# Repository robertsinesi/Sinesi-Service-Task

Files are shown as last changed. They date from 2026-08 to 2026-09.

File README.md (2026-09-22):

# KLM SRAM Expansion — Service Task

Belle II KLM service work · Instrumentation Development Lab, University of Hawai'i at Mānoa

## Overview

The KLM scintillator readout currently shares a single SRAM between the Bus A and
Bus B firmware modules through the SCROD FPGA. During multi-strip hits, pedestal
fetching becomes the rate-limiting step in waveform processing. This project adds
a second SRAM on an auxiliary daughtercard so each bus has its own memory path,
along with the power-distribution hardware needed to supply it.

Three boards make up the system:

| Board | Function |
| --- | --- |
| **Aux SRAM daughtercard** | Mounts to the spare 80-pin mezzanine connector on the scintillator motherboard; carries the second SRAM and a local 3.3 V regulator |
| **RTM +5 V board** | Rear transition module; taps +5 V from the crate backplane, fuses it, and feeds the wiring harness |
| **2-pole fanout board** | Splits the 12 AWG trunk into 22 AWG drops, one per SRAM card |

**Board design credit:** all three boards were designed by Chris Ketter (UH Mānoa),
with contributions from Horacio Ledesma. My role is prototype testing and design
finalization.

## Scope of this qualification task

Testing and validation:

- Test the prototype SRAM expansion board on the UH KLM testbench
- Test the associated RTM and power-distribution boards
- Verify electrical connections and power delivery across the full chain
- Confirm correct operation with the dedicated SRAM firmware

Finalization:

- Feed prototype results back into the board designs
- Help finalize assembly procedures ahead of the production run

Superseded board revisions are kept in the `Old_Boards_Moved_<M-D-YY>/` folders (dated by when they were superseded, each with a short README); current files are in `Finalized-Boards/`.

## Deliverable

- Finalized board designs
- Production of the boards
- Installation of the boards

## After the qualification task

Continued contribution to board production, testing, and installation as part of
ongoing KLM service work.

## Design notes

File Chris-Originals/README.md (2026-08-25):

# KLM SRAM Exp

## KLM SRAM Upgrade project
We are using a spare 80-pin connector on the motherboard to double the amount and bandwidth of SRAM available to our FPGA.

## Firmware
The new firmware for this project has been created in the main SCROD FW repository under the branch feature/SRAM_upgrade.

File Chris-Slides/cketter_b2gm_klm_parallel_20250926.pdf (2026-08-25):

Chris Ketter & Horacio Ledesma University of Hawaii at Mānoa

## KLM Scintillator SRAM Expansion

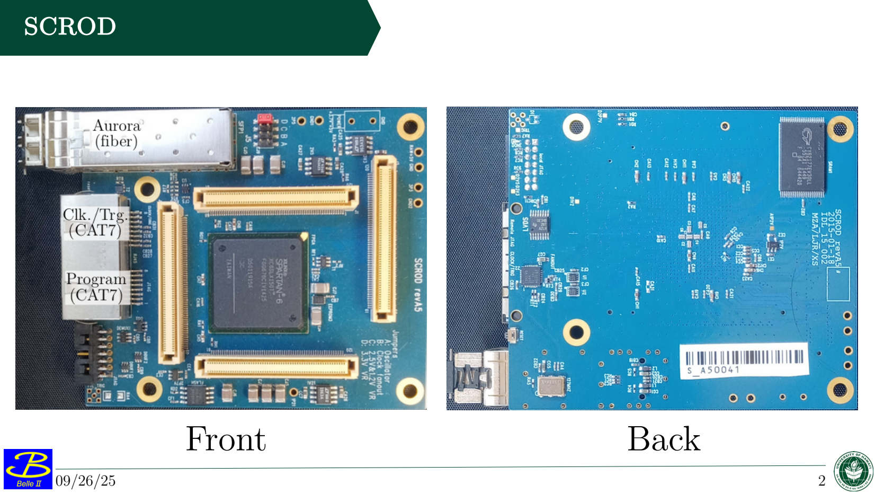
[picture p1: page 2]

09/26/25 | 2

SCROD

Front | Back

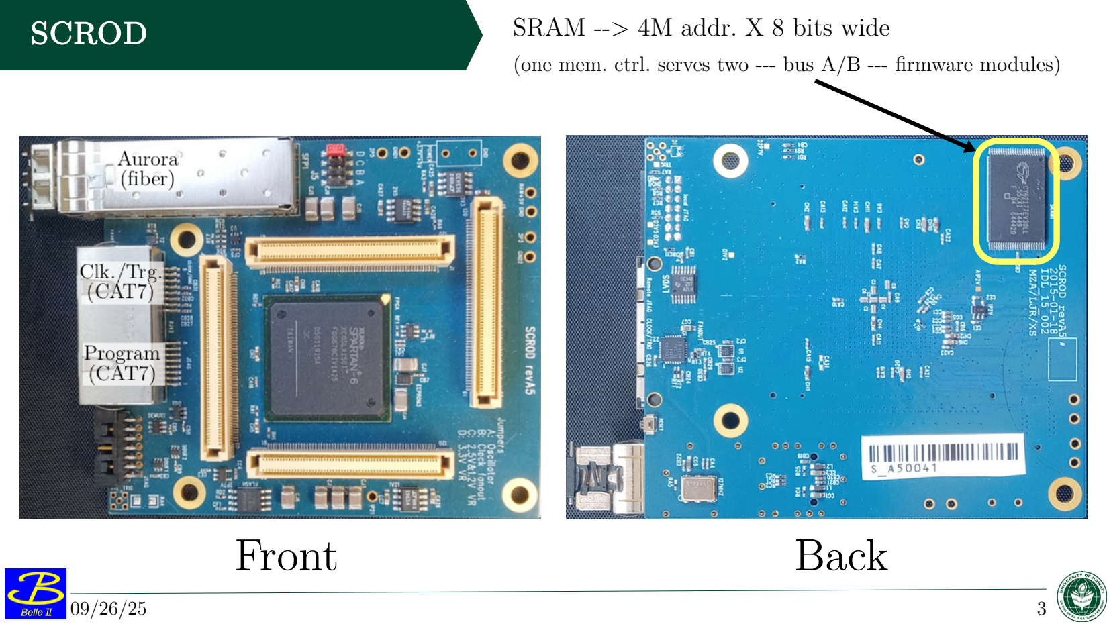
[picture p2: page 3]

SCROD | SRAM --> 4M addr. X 8 bits wide (one mem. ctrl. serves two --- bus A/B --- firmware modules)
Front | Back

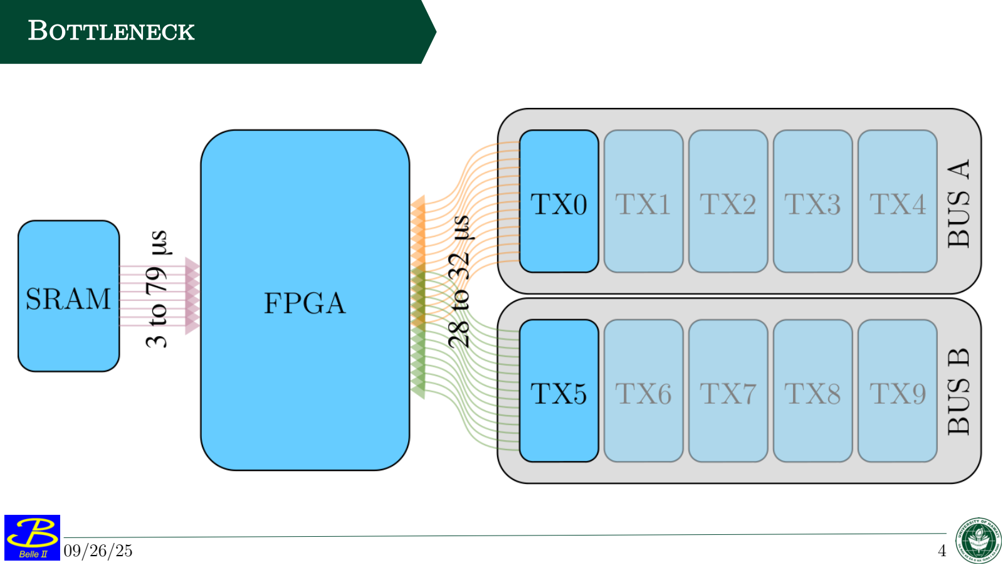
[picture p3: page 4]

Bottleneck

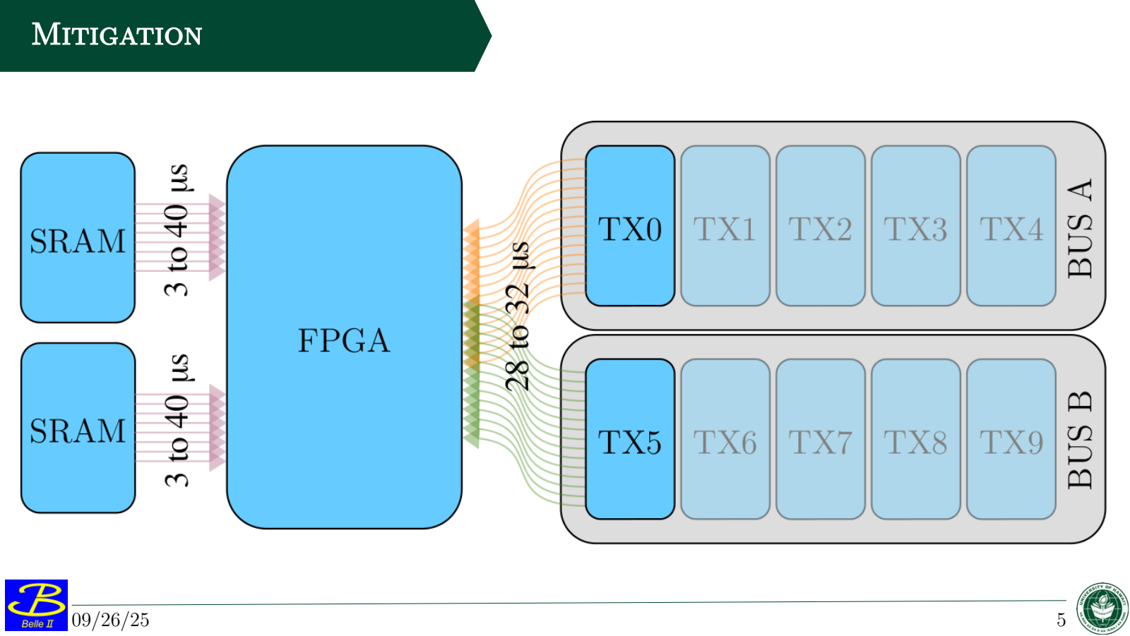
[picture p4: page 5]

Mitigation

SCROD SRAM Expansion
Board

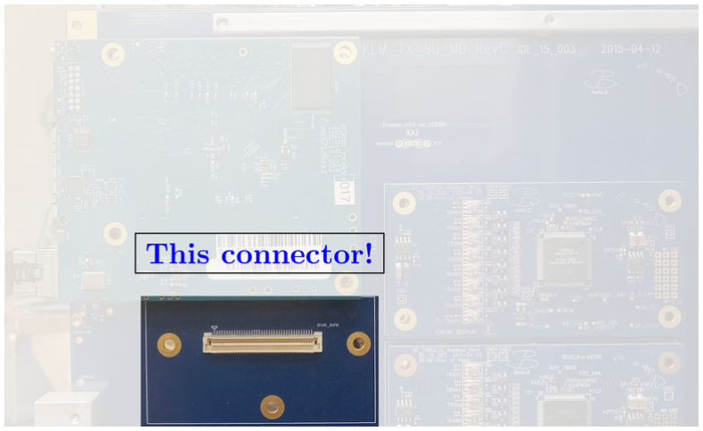
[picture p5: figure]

Important for multi-strip hits wherein pedestal fetching
becomes the bottleneck
The US-Belle II operations budget confirmed $15k for the project

Design requirements

At least 2M X 8 in memory depth
As fast as existing SRAM
Installation must be possible without uncabling (and thereby possibly damaging) readout electronics
External 3.3 V power supply must meet same installation criteria

Design requirements
At least 2M X 8 in memory depth
As fast as existing SRAM
Installation must be possible without uncabling (and thereby possibly damaging) readout electronics
External 3.3 V power supply must meet same installation criteria

(Extra --- wish list --- item: Can we install standoffs under SCROD at the same time?
→Recall persistent issue with SCRODs coming unseated!)

## Ease of installation?

Access Test (Last July)

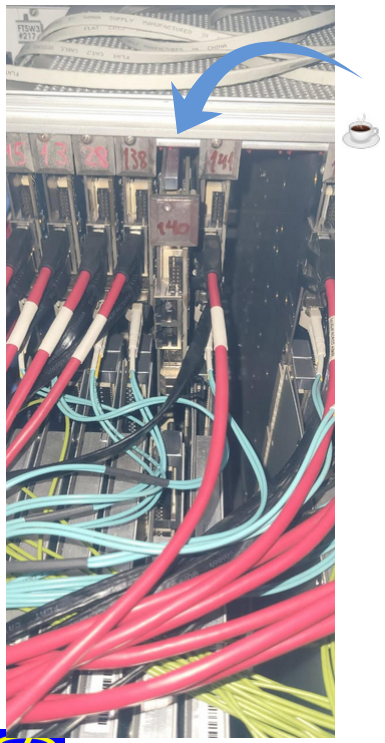
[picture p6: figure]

Slid out a central
board in EB0

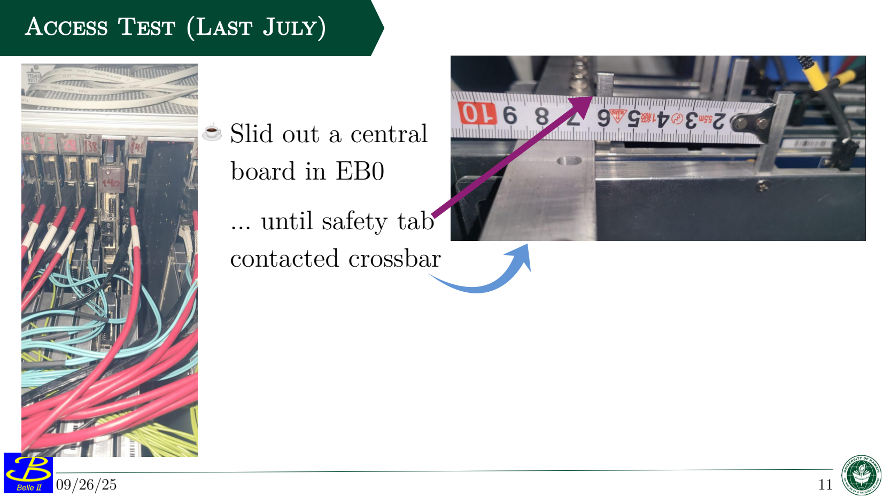
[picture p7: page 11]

Access Test (Last July)

Slid out a central
board in EB0
... until safety tab
contacted crossbar

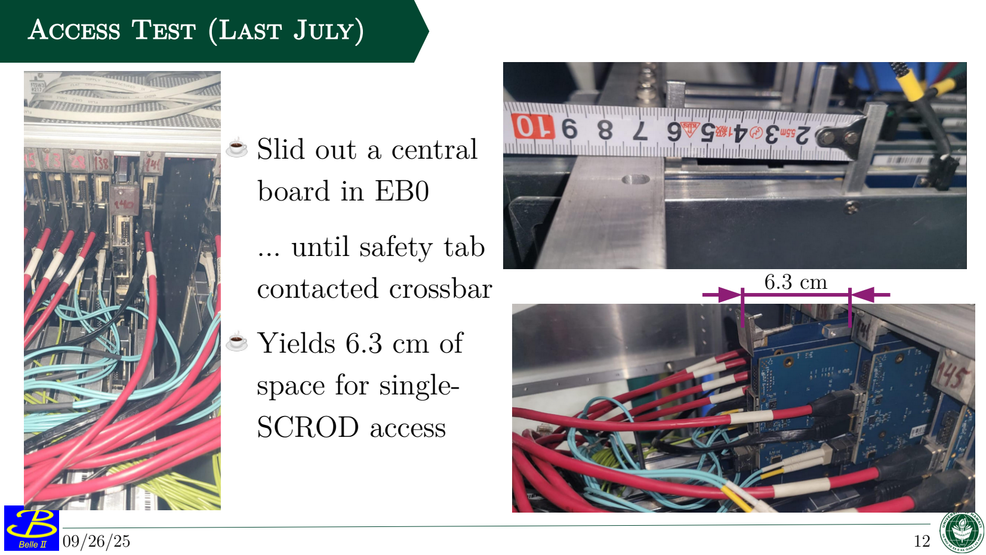
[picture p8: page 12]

Access Test (Last July)

Slid out a central
board in EB0
... until safety tab
contacted crossbar
Yields 6.3 cm of
space for single-SCROD access

6.3 cm

Access Test (Last July)
Definitely enough room to access mezzanine connector for SRAM expansion board
Can also install at least one standoff between SCROD and motherboard --- two diagonally would be much much better
But, we had an issue with
RHIC unplugging from
motherboard

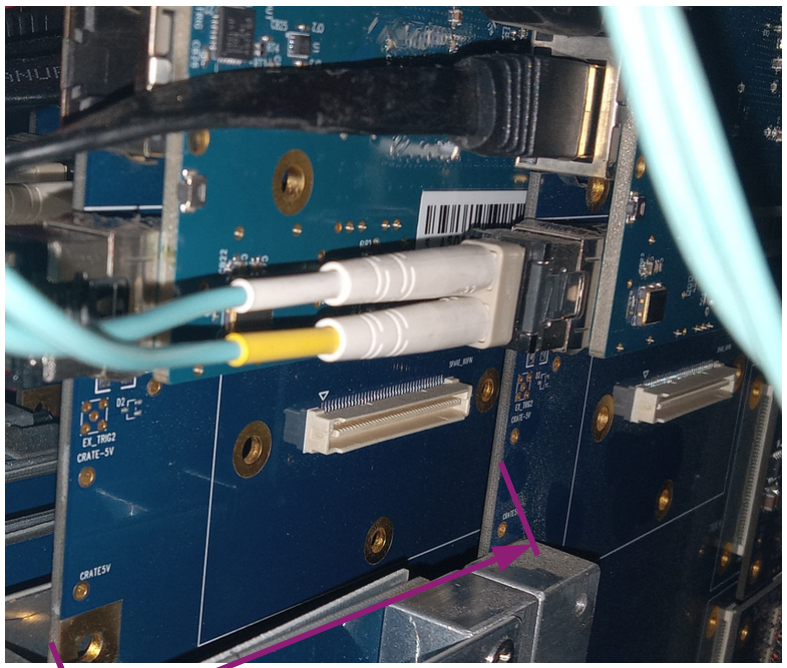
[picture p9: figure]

6.3 cm

Tabletop Investigation

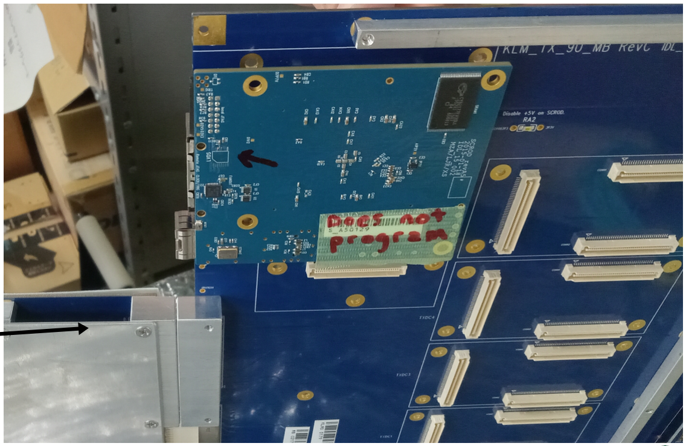
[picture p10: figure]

Checked situation
using broken FEEs
in storage
Plan to fabricate
clamp to hold
motherboard and
RHIC together
during removal

Tabletop Investigation

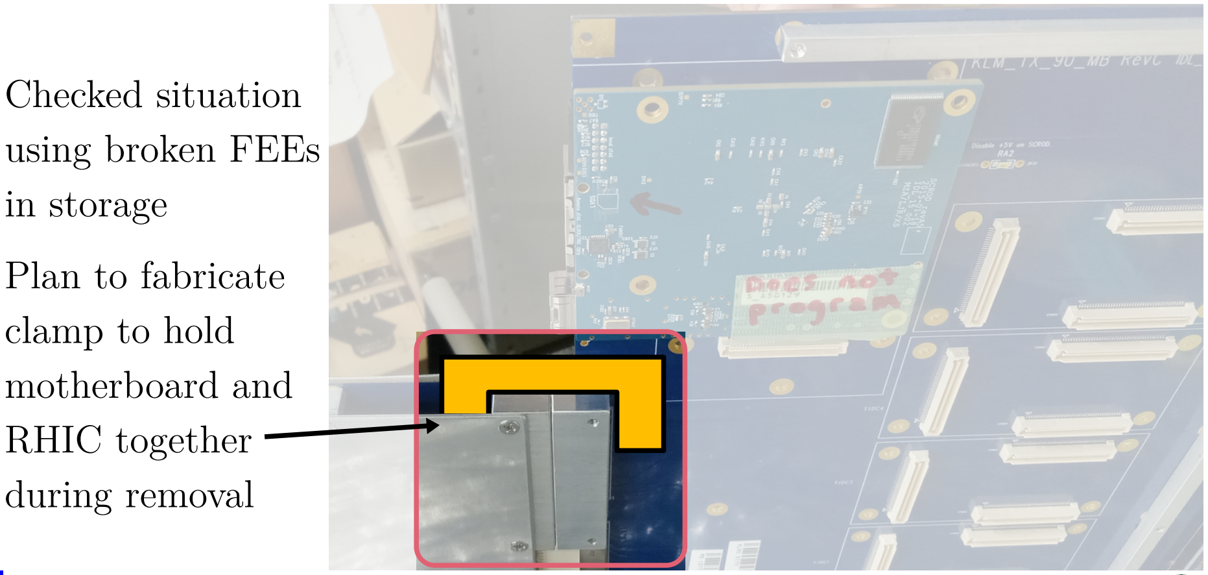
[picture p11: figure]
Checked situation using broken FEEs in storage Plan to fabricate clamp to hold motherboard and RHIC together during removal
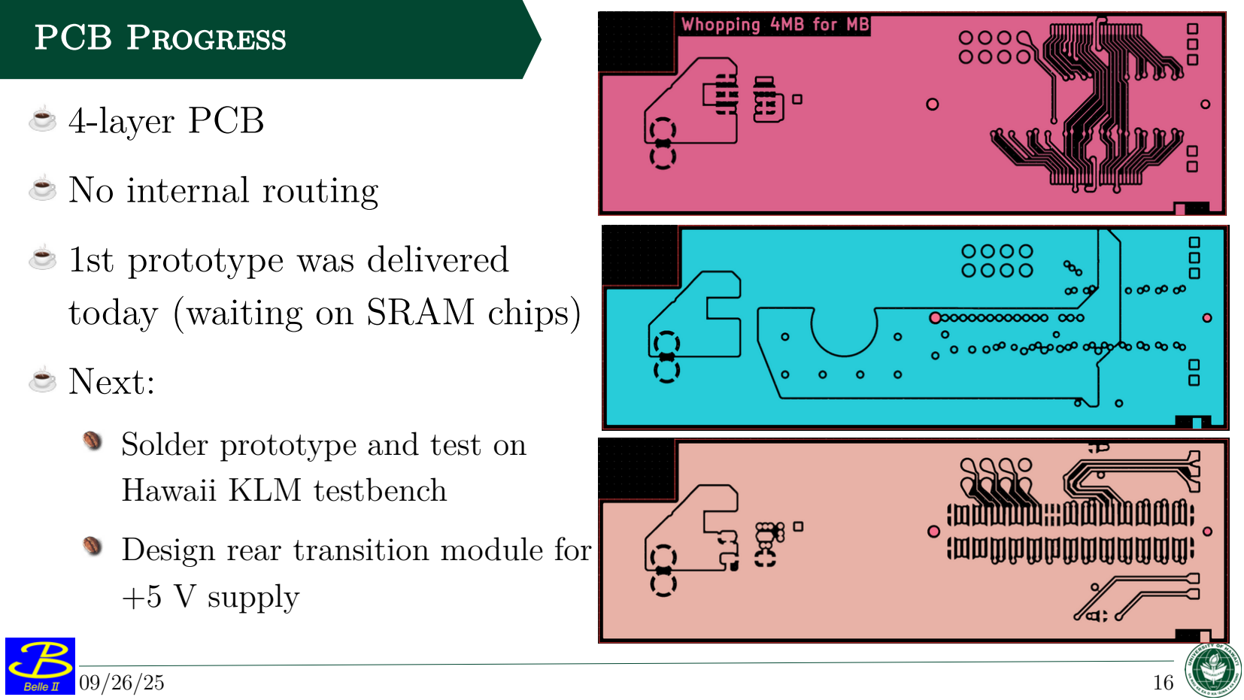
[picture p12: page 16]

PCB Progress
4-layer PCB
No internal routing
1st prototype was delivered today (waiting on SRAM chips) Next:
Solder prototype and test on Hawaii KLM testbench
Design rear transition module for +5 V supply

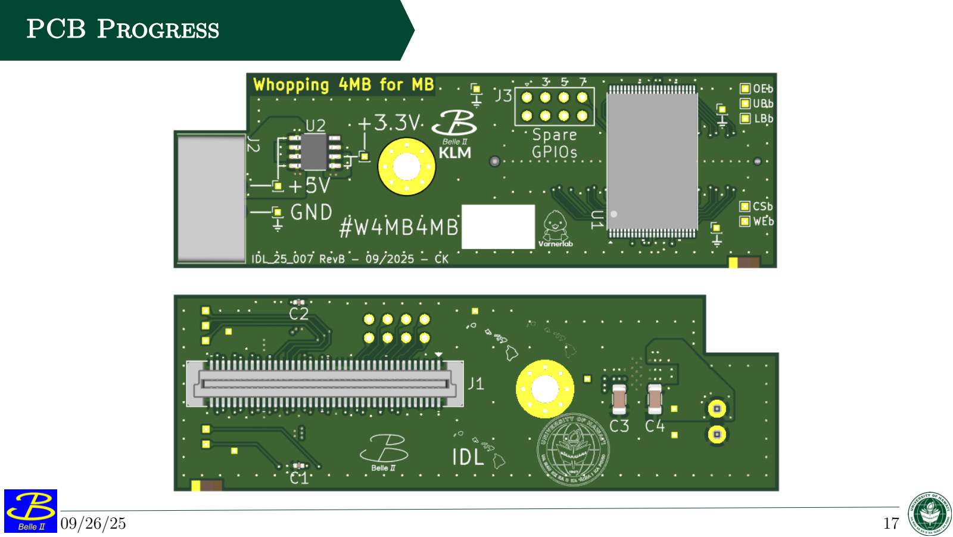
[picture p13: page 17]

PCB Progress

## 3.3 V Supply Location

KLM Scint. Crate Rear

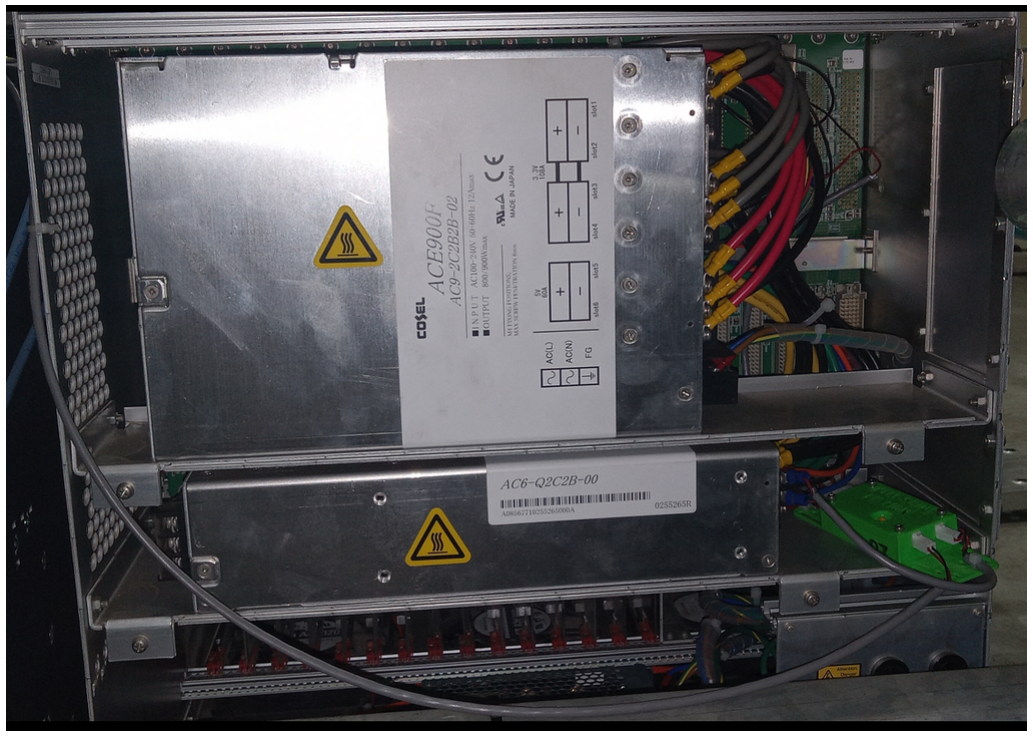
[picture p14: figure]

Looking for easy,
clean way to get low-voltage power for
SRAM expansion
boards ...
Inspected rear of
crate for options

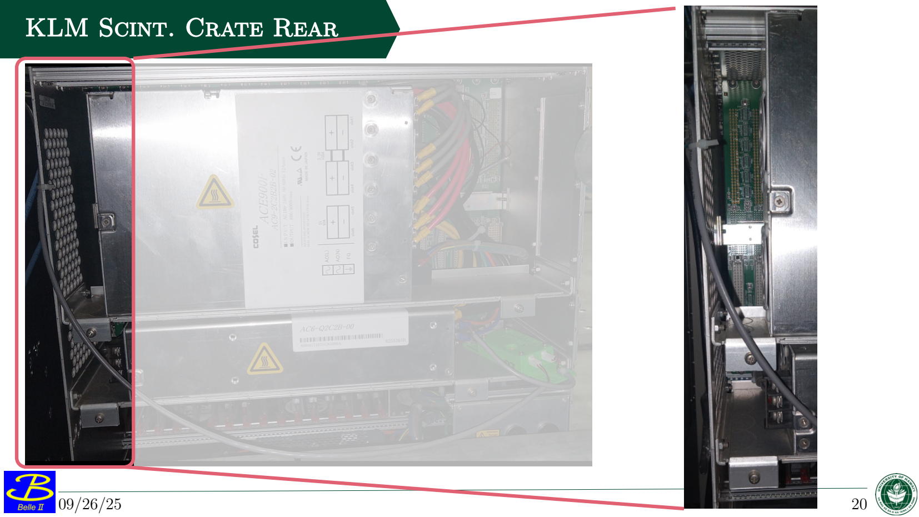
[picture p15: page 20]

KLM Scint. Crate Rear

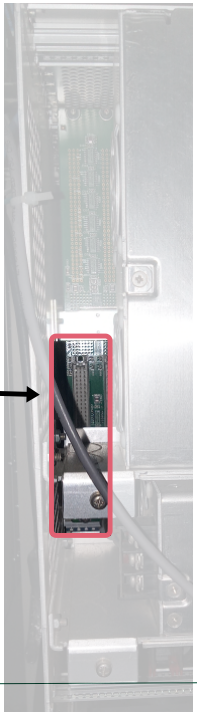
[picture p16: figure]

KLM Scint. Crate Rear

Free connector here with
straight shot out of back of crate for a wiring harness

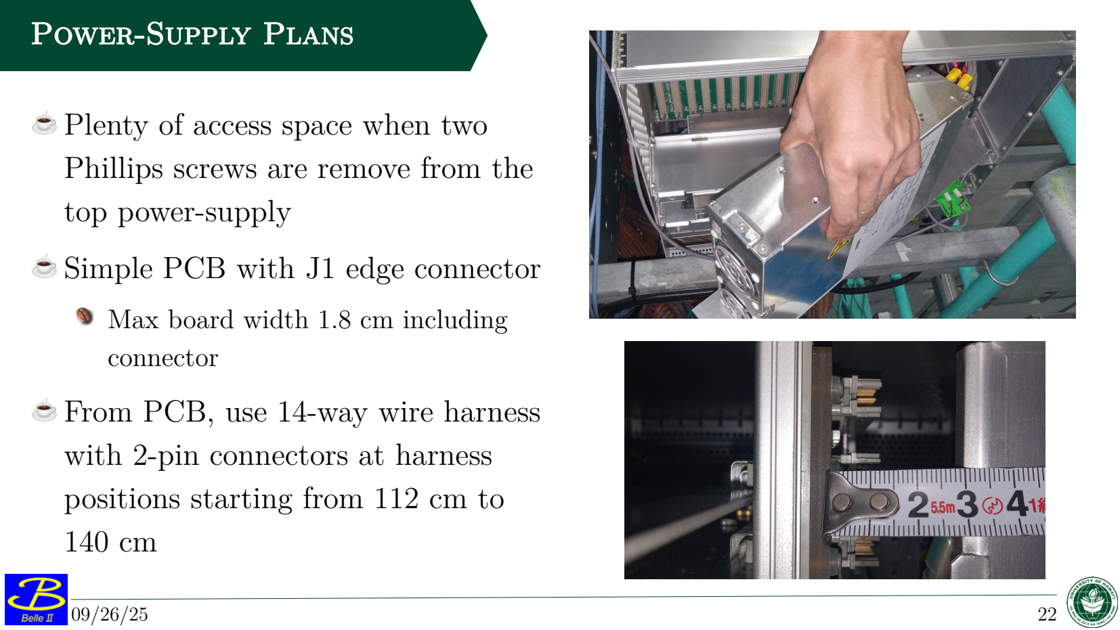
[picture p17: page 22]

Plenty of access space when two Phillips screws are remove from the top power-supply
Simple PCB with J1 edge connector Max board width 1.8 cm including connector
From PCB, use 14-way wire harness with 2-pin connectors at harness positions starting from 112 cm to 140 cm

Power-Supply Plans

## Firmware

Firmware Modification

New feature branch SRAM_upgrade in
KLM scintillator firmware repository (https://gitlab.desy.de/b2klm/klm_scrod)
Removed bus A/B arbiter from PedestalFetcher.vhd and PedestalWriter.vhd
- Duplicated these "Pedestal" modules and connected one to bus A and one to bus B Connected nets from spare connector on the motherboard to the firmware and cascaded signals down to "Pedestal" modules

Firmware Simulation
Pedestal measurement
Full (top-level) simulation
Python script generates random TARGETX ADC data and calculates expected average pedestal
measurements for every storage cell
- Expected 8-bit SRAM values written to text file
Xilinx ISIM writes measured 8-bit SRAM values to another text file Python analysis script compares both text files and plots results

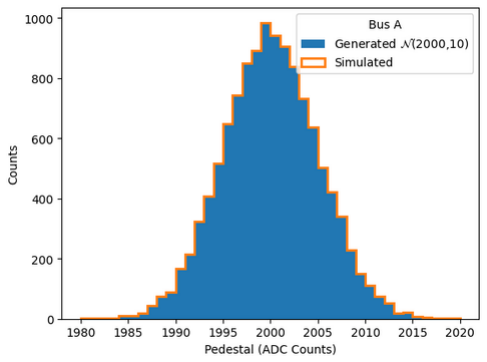
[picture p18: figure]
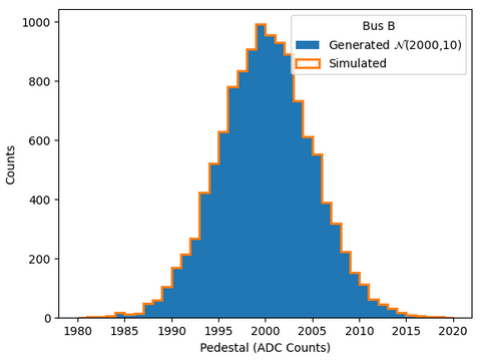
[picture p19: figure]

## Summary / Next Steps

Hardware inspection at KEK validated installation feasibility without uncabling FEEs
Acquired measurements for auxiliary components (power distribution) New SCROD firmware feature branch developed and verified in simulation Prototype delivered --- ready for soldering and hardware testing
Plan to make 164 SRAM boards and 15 power supply boards (all KLM + 20% spares)
Nominal installation planned for next summer

## Firmware

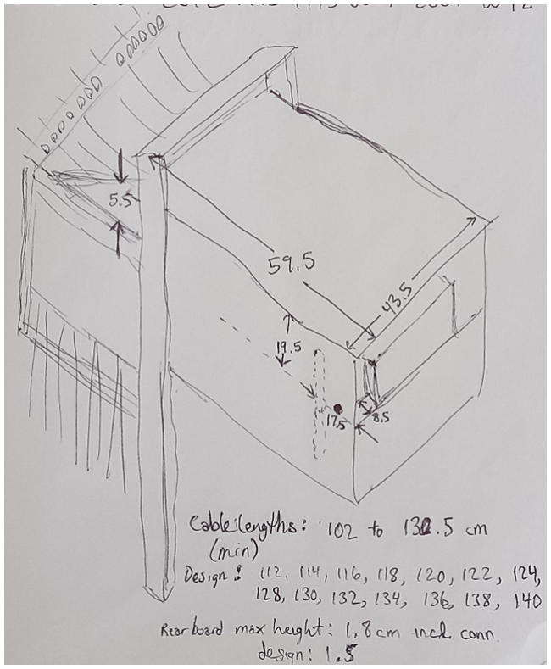
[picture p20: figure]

112 to 140 cm (includes 10 cm slack at SCROD side)
- Bend up at 17.5 cm
- Bend fwd after 19.5 cm
- Bend down after 59.5 cm
- First connector after 5.5 + 10 cm
- Additional connector every 2 cm
(7 conn., then 4 cm gap, then 7 more conn.)
Rear power board uses J1/J2 connector Board with edge connector should be 1.5 cm wide
Output harness should egress from the top of the boards rear edge (see right pic. in slide 19)

Wire Harness Dimensions

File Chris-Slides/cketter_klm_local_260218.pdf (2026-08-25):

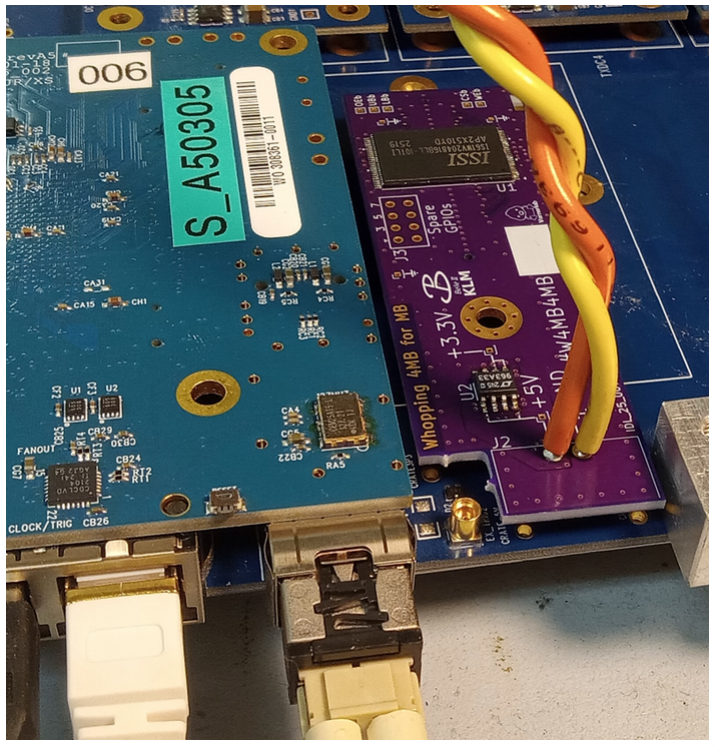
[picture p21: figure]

02/18/26 | KLM Weekly | 1

Last time: Programmed lane 1 SCROD with bitfile klm_scint_v3201.bit compiled last July --- New SRAM not working Probed testpoints
Nothing measured as expected
Found problem
klm_scint_v3201.bit was written before the board was made --- we did not know the pinout at that time
Now works great

## SRAM Update

## Test Results

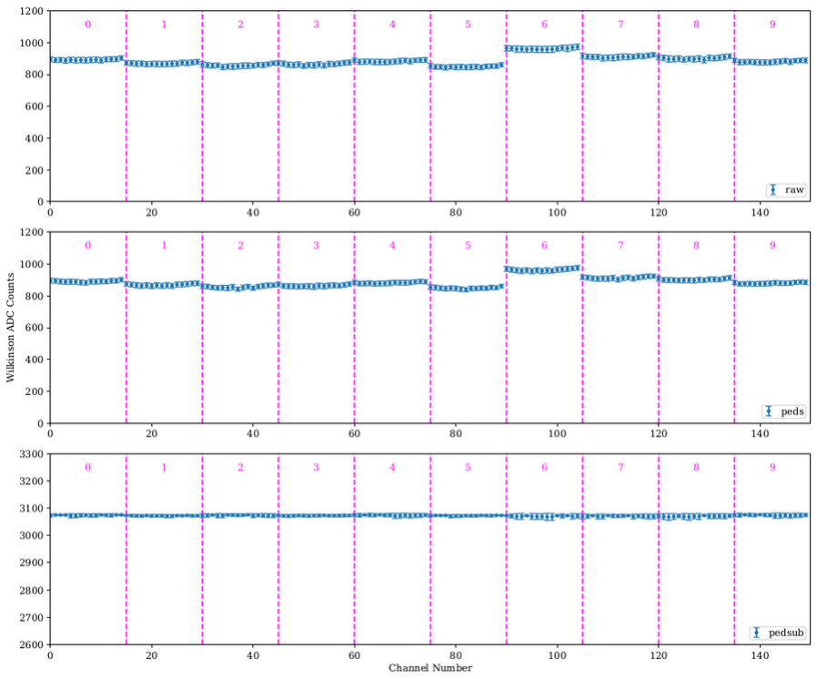
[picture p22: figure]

## Version Log

v3201
First compile of SRAM upgrade firmware v3202
Tied BUS_REGCLR to GND as in master branch
v3203
Fix pin mapping in UCF file
v3301
Merge with vFE33 and
feature/ramp_settle
- ramp_settle feature not working as anticipated

## Version Log

v3201
First compile of SRAM upgrade firmware v3202
Tied BUS_REGCLR to GND as in master branch
v3203
Fix pin mapping in UCF file
v3301
Merge with vFE33 and
feature/ramp_settle
- ramp_settle feature not working as anticipated

Comments on feature/ramp_settle Symptom was lower than nominal ADC counts for 2nd digitization window whenever 1st digitization window only shifted out last 4 samples
Intention was to delay BUS_RAMP signal if it did not have enough settle time from the last activation
Result is higher than nominal ADC counts for 2nd digitization window under same conditions as above
Hypothesis: so-called BUS_RD_ENA signal actually starts gray-code counter
I will either move the ramp delay up the FW hierarchy or encapsulate the BUS_RD_ENA signal under the same delay logic --- whichever is cleaner

## Remaining Tasks

SRAM Expansion PCB
Finalize +5V connector choice
(Cheap, easy, secure, non-interference) Double-check PCB design
(Characteristic impedance? Image-current path? Happy with silkscreen?)
Order 3 more or order full production run Design RTM board for +5V supply Design wire harness
(Determine gauge from power budget, appropriate flexibility or stiffness, how to sheath and preform bends)

Investigate feasibility of securing SRAM PCB with standoff
Enough threads for proper engagement? Necessary screw sizes available to fully utilize threads?
Screw heads don't interfere with neighbor boards?
Investigate SCROD fastening hardware at same time
Same considerations as above
Ease of installation?
Order all hardware, wire spools, and ICs Design clamp tool for easy MB removal

## Other Activities

Booked all my KLM shifts for 2026a all in next few weeks
Make slides for KLM group meeting next week
Travel to Japan? (Should I?)
Way behind on CR shifts
May want to test-fit prototype RTM power supply board and wire harness before constructing all units

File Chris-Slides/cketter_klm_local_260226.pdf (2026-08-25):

Chris Ketter
Horacio Ledesma, Keisuke Yoshihara

University of Hawaii at Mānoa

# KLM SCROD SRAM Expansion Feb. 2026 Update

02/26/26 | KLM Weekly | 2

### Recall

In events with multi-strip hits, SRAM access for fetching stored pedestals can become the bottleneck in waveform processing Scintillator motherboard has spare 80 pin connector with nets connected to FPGA GPIOs
Got approval to create SRAM expansion PCB
Now each axis (called Bus A / Bus B on motherboard) will have its own SRAM chip for pedestal storage
New scheme will halve the time for pedestal access


Prototype board designed
1st article soldered together
Still finalizing choice for 5V connector New firmware prepared last summer by Horacio and I
After modifying the pin mapping in firmware, our modified SRAM access logic in the SCROD firmware worked great

### SRAM Update

### Test Results (128

kSamples) | Bus B (New SRAM)

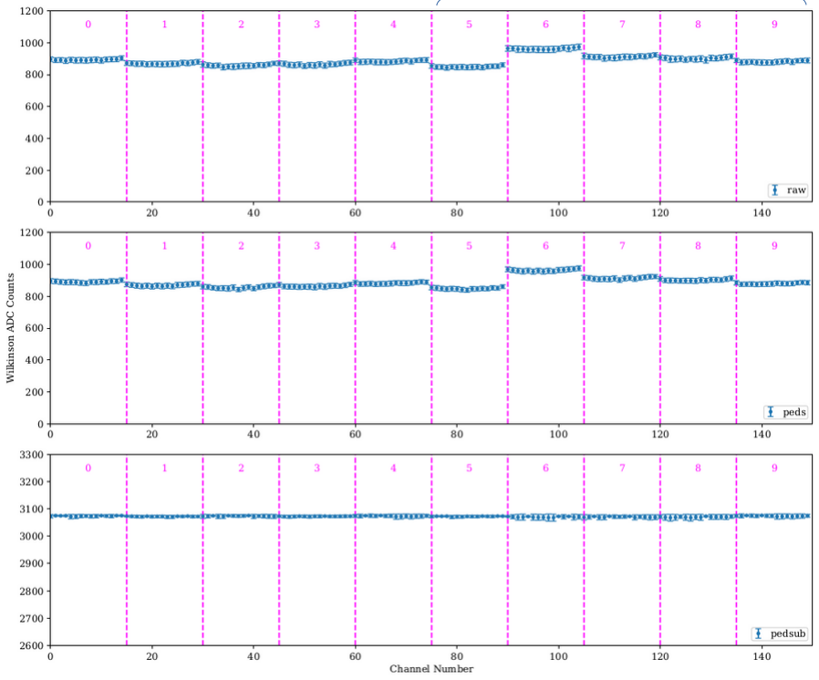
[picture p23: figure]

Results are
consistent with
similar scan using
only the original
SRAM chip for
pedestal storage!

### Version Log

v3201
First compile of SRAM upgrade firmware v3202
Tied BUS_REGCLR to GND as in master branch
v3203
Fix pin mapping in UCF file
v3301
Merge with vFE33 and
feature/ramp_settle

What's that?

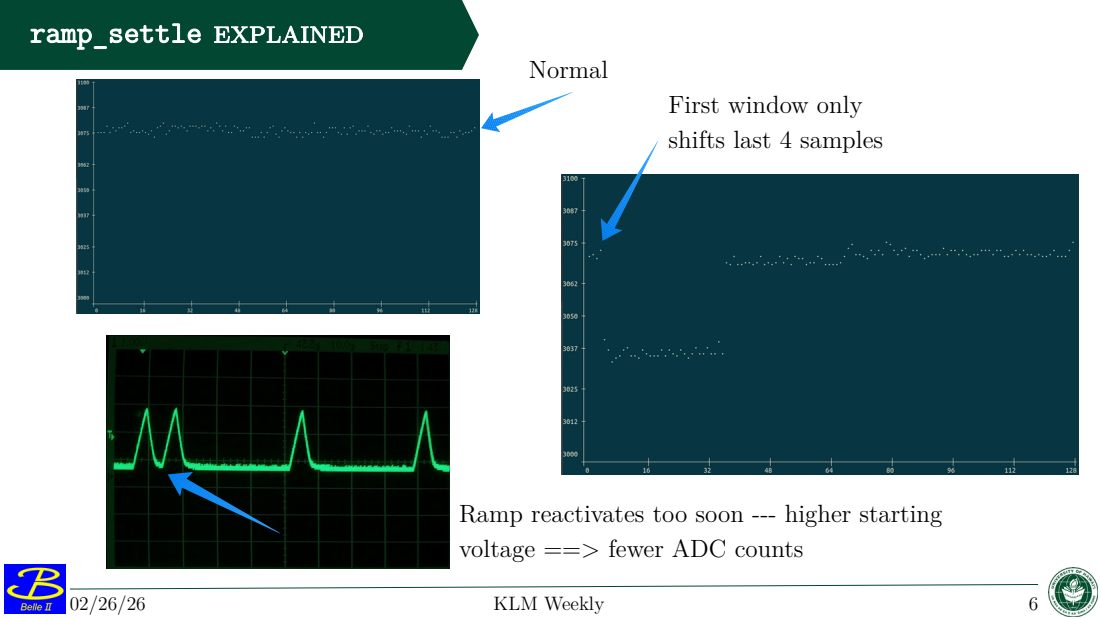
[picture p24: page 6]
ramp_settle explained; Normal

First window only
shifts last 4 samples

Ramp reactivates too soon --- higher starting
voltage ==> fewer ADC counts

### Version Log

v3201
First compile of SRAM upgrade firmware v3202
Tied BUS_REGCLR to GND as in master branch v3203
Fix pin mapping in UCF file
v3301
Merge with vFE33 and feature/ramp_settle
- ramp_settle feature not working as anticipated (Wilkinson counter starts too early)

v3401
Merge with vFE34
v3402
Refactor feature/ramp_settle
(delay BUS_CLR and BUS_RD_ENA along with BUS_RAMP)

Now 2nd-window ADC performance is restored! ... but

Latest bit file shows outliers in pedestals from new SRAM (hardware seems okay --- need to investigate further)

### Remaining Tasks

SRAM Expansion PCB
Finalize +5V connector choice
(Cheap, easy, secure, non-interference) Double-check PCB design
(Characteristic impedance? Image-current path? Happy with silkscreen?)
Order 3 more, solder & test, then order production run
Design RTM board for +5V supply Design wire harness
(Determine gauge from power budget, appropriate flexibility or stiffness, how to sheath and preform bends)

Investigate feasibility of securing SRAM PCB with standoff
Enough threads for proper engagement? Necessary screw sizes available to fully utilize threads?
Screw heads don't interfere with neighbor boards?
Investigate SCROD fastening hardware at same time
Same considerations as above
Ease of installation?
Order all hardware, wire spools, and ICs Design clamp tool for easy MB removal

### Timeline

Jan | Feb | Mar | Apr | May | Jun | Jul | Aug | Sep | Oct | Nov | Dec

Soldered 1st board

| Testing
| | Finalize board designs
| | | ------------Production run------------(Send to board fab. house)
| | | Build Wiring Harnesses in house (12 required) | | | ------------Installation------------

# Backup

### Operations

On shift all week
Data Concentrator dc13
Installed in BF0
3rd layer frequently drops in efficiency after certain beam aborts
- Twice yesterday, the first saw 1300 mrad to beampipe diamonds
- Recovers after reprogramming
- Hit-channels distribution shows comb-like structure (as though every other channel has an issue)
- Maybe we should replace the RPC front-end board ...
BB6 3rd layer shows similar hit-channel distribution!


### Pedestal Outliers


Top: Bus A
Bottom: Bus B (new SRAM)
Streaming pedestal values only (direct from SRAM chips to debug wave FIFO)
Four outliers in this example waveform (typical)
Reverting to previous bitfile fixed issue, so new hardware is not the issue
Firmware logic changes completely unrelated Suspect cross-talk from unconstrained GPIO pins --- will investigate on oscilloscope

Compiled v3403
Grounded spare GPIOs that are routed to SRAM expansion
Outlier problem fixed
ADC drop in 2nd digitized window seems much much better
- Basically perfect most of the time, but a few examples of a slight dip in the 2nd window (~10 ADC counts as opposed to sometimes 40 or more seen previously)


v3403

### Ideas

Want to try adding pulldown resistors to SR Clock and TARGETX DO
Can we shift out data faster?
Does it change the current draw?

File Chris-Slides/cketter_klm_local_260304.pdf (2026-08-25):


03/04/26 | KLM Weekly | 1

Last time: Prototype PCB fully working These slides
Condense information about requirements for rear transmission module (RTM) that supplies power and requirements for harness

### SRAM Update

### Back Side of KLM COPPER crates


Upper power
supply

Lower power
supply

Board will go here; Planned as a rear transition module (RTM); reverse side of a crate's backplane; Lower power supply tray as deeper than; planned location of the board; Rear Power Board

Effectively, it's a board that plugs into the

that of the upper putting it closer to the

Upper power
supply

Lower power
supply


Upper power
supply easily pivots
out of the way
after removing two
Phillips-head
screws

### Installation Ease


### Board Orientation / Wire Harness Route

Board was envisioned as a right-angle 96-position VME backplane connector (male housing / female pins) and two plated through holes for soldering the +5 / GND wires of the wiring harness
Tape measure shows the path through which the wiring harness will egress


Envelope is 1.8 cm from the lower power supply tray to the edge of the connector (this is how much space we have to maneuver our board into place without removal of the metal tray that the lower power supply sits on

### Space


### Connector

Although board was envisioned as having a right-angle connector (1195-2893-ND), we actually have many of the straight version in stock (1195-1197-ND)

This would also be possible, and perhaps simpler
A 3rd option is to just connect ring terminals to the main output of the +5 V power supply

I think we disfavored this because it's not proper --- those should connect the power supply to the bus bar and nothing else!


### Pinout

+5 V is on pins 1, 13, and 32 of row B GND is on pins 2, 12, 22, and 31 of row B Every other pin should be left unconnected in the design of the rear power board

### Cable Selection

SRAM Expansion PCB prototype draws 16 mA on the testbench (TODO: recheck current during continuous operation) Accordingly, EKLM FWD crates will draw an additional 224 mA from the +5 V net Assuming safety factor of 4, current draw is 1 A

20 AWG copper wire is rated for 11 A and has resistance .01015 mOhms / ft

At 5 ft harness length, voltage drop would be 50 mV (realistically 12 mV w/o safety factor)

Smaller than 20 AWG may be too weak mechanically, e.g. if it were snagged Actually, I'd like 10 AWG or 8 AWG from the rear power board and branch out to 20 AWG at each of the 8 (barrel), 12 (EBWD) or 14 (EFWD) drops per harness

10 AWG is about 10 x the area of 20 AWG 8 AWG is about 16 x the area of 20 AWG


### Harness Specification

Heavier gauge wire (e.g. 10 AWG) should be 95 cm in length
90° bends should be formed at 16.5 cm, 31 cm, and 90.5 cm
The last two should have protection against chaffing against the crate
Drop wires (i.e. 20 AWG) should be in lengths of 12, 14, 16, 18, 20, 22, 24, 28, 30, 32, 34, 36, 38, and 40 cm
Note the 4 cm gap between the 7th and 8th
For the four crates in the barrel, the lengths are yet to be determined
Probably something like 14, 16, 20, 22, 28, 30, 36, 38 cm

### Additional Considerations

Probably we want a fuse
either a polyfuse or a serviceable one-time fuse

●


if one-time fuse, we can maybe use an inline fuse
1.5x the operating current is typical (rounded up to next available size)
I like 4x actually --- large enough to never have problems yet small enough to prevent fires
Further, our choice of wire and sheathing should meet KEK fire code standards
(How do we even find this information?)


### SRAM PCB Connector

Quoted connector may interfere with nearby aluminum bracket
Difficult to find slim 2-position connectors,


plus, if I order something weird, we may not have the right crimp tool
Chosen connector must have a latching system Latch should be on top to avoid nearby aluminum bracket
Does not have to be super slim if we extend SRAM PCB to extend past edge of motherboard
- Connector can then be on bottom (facing motherboard) so it does not overlap with adjacent motherboard

Now considering Molex 4-position connectors (WM4302-ND, WM2002-ND) We use Molex quite extensively and have most of the tools
4 pins provide 2x redundancy
$0.45 per pair ($0.30 / $0.15)
Friction lock

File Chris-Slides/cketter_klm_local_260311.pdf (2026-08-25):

03/11/26 | KLM Weekly | 1

## KLM SCROD aux SRAM

(v3)

Change Log
Extended pad lengths on the mezzanine connector, the SRAM chip, and both sizes of capacitor for ease of soldering
Cleaned up title, silkscreen, etc.
(new Varnerlab logo more prominant!) Rerouted many instances of "via in pad" for ease of soldering
- Had to shift SRAM and touch up all routing to keep ground-planes continuous
Created and placed new 4-pin Molex power connector and flipped connector to back side

Investigated image current paths for all traces
- 3 violations --- I could not fix them but they are not time-critical signals (OEb, UBb, and LBb)
- Made sure ground vias are placed close to all signal vias
Made board longer to create envelope for connector in front of motherboard
Made board shorter (y-direction) to minimize surface area (e.g. cost)
Removed pointless stitching vias and added grid vias in open spaces to decrease thermal resistance between planes

## To Do


Double check motherboard edge relative to design to ensure clearance for new connector
Shift power connector down and decrease tab height (short portion of PCB) to give maximum clearance for external trig connector and MB-RHIC Al bracket

## Front


## Back


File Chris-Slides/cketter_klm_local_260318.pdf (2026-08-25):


03/18/26 | KLM Weekly | 1

### Finished Tasks

Uploaded all past UH-KLM slides to Indico Fixed authentication issues with klm_hi_tb_manual gitlab repository (https://gitlab.desy.de/cketter/klm_hi_tb_manual) and pushed latest changes
Visibility is "private"
KLM SCROD aux SRAM
Moved power conn. down and shrunk board height
Added layer showing motherboard edge in layout (coordinates extracted from MB gerbers)
Pushed revC to klm-sram-exp gitlab repository (https://gitlab.desy.de/cketter/klm-sram-exp)
- Set visibility to "public"

Testbench manual members


### Board Model (ready for fab)

### Wire Harnesses

Finalized choices for wire harness materials
Updated rest of bill of materials (BOM)
Added links and computation of actual cost (ignore things in Varnerlab stock) Estimated cost $6200 (but uncertainty about board assembly)


### Assembly

This was my first idea for soldering 28 leads of 22 AWG wire to a single 12 AWG wire
Soldering and heatshriking will be terrible


### Assembly

This was my first idea for soldering 28 leads of 22 AWG wire to a single 12 AWG wire
Soldering and heatshriking will be terrible Next plan
use 10-12 AWG butt connector
- 14 wires fit nicely, but need a second for next 14 wires --- still investigating what to do with the 12 AWG end
- Would like non-insulated butt connectors so I can solder them


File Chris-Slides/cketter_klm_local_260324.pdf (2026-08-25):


03/25/26 | KLM Weekly | 1

### Power Fanout (2 pole)

12 mm X 47 mm
Fans out black (Bk) and white (W) wires from two 12-AWG lines to sixteen 22-AWG jumpers (12" long with other end precrimped) w/ 1cm spacing
Includes strain relief holes for the more fragile 22-AWG wires
Makes batch soldering easier --- thread all 16 at once, strip and install all 16, then solder all 16 Heatshrink whole board after assembly
Total boards needed: 36
EFWD (4*4), EBWD (4*3), BKLM (4*2)


### 2, 3, & 4-way 12 AWG fanout

WAGO butt splices are super easy to use and can be disconnected later if problems arise
Need 24 total

Basic Idea (for 1 of 36); Thread, strip 2-3; solder (16x) Solder (2x); Gather 2w/2bk & cover with sheath (4x)

mm, insert, and

Strip and clamp
1w/1bk 12 AWG

Snap 2w/2bk crimped
terminals into connector (4x)

Stop ends from fraying
with two pieces of heat
shrink (8x)

### Assembling Harnesses

Quantities
All four Barrel KLM crates each need two fanout boards All four EBWD crates each need three fanout boards
All four EFWD crates each need four fanout boards

●

two fully populated (with four) and two populated with only three jumper harness assemblies for a total of 14 per crate
Each w/bk pair of 12 AWG wire segments from the WAGO connectors to their respective fanout board can be cut about 8 cm longer than the previous pair
This will make all of the jumper harnesses well aligned with their respective "KLM aux SRAM" boards


### Rear Transition Module (RTM) Power Supply PCB

"+5VP" = +5 V Fuse Protected
Plan to solder our 12 AWG w/bk wires directly to this PCB
Layout includes layer "User.1" to show layout of next backplane connector 0.8 inches from the first
A 1 A fuse should suffice, but we need to double check the current draw when the SRAM is continuously being used to establish a peak value
Expected draw is < 250 mA, so 1 A fuse provides an adequate safety factor

### Installing Harnesses

The 2-conductor shielded twisted 12 AWG cable needs to be cut to length prior to soldering to the RTM power supply PCB
I would cut the prototype to 1.2 m and check the fit
The RTM should be soldered to the cable prior to installation
After installation, the cable should be secured to the crate to prevent the RTM from being dislodged if some portion of the cable is snagged by someone working nearby
Of course snagging should be mitigated by thoughtful routing, but it's a no-brainer to properly strain relieve this cable if possible

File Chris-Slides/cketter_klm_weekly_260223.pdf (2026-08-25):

Chris Ketter
Horacio Ledesma, Keisuke Yoshihara

University of Hawaii at Mānoa

# KLM SCROD SRAM Expansion Feb. 2026 Update

02/23/26 | KLM Weekly | 2

### Recall

In events with multi-strip hits, SRAM access for fetching stored pedestals can become the bottleneck in waveform processing Scintillator motherboard has spare 80 pin connector with nets connected to FPGA GPIOs
Got approval to create SRAM expansion PCB
Now each axis (called Bus A / Bus B on motherboard) will have its own SRAM chip for pedestal storage
New scheme will halve the time for pedestal access


Prototype board designed
1st article soldered together
Still finalizing choice for 5V connector New firmware prepared last summer by Horacio and I
After modifying the pin mapping in firmware, our modified SRAM access logic in the SCROD firmware worked great

### SRAM Update

### Test Results (128

kSamples) | Bus B (New SRAM)


Results are
consistent with
similar scan using
only the original
SRAM chip for
pedestal storage!

### Version Log

v3201
First compile of SRAM upgrade firmware v3202
Tied BUS_REGCLR to GND as in master branch
v3203
Fix pin mapping in UCF file
v3301
Merge with vFE33 and
feature/ramp_settle

What's that?

ramp_settle explained; Normal

First window only
shifts last 4 samples

Ramp reactivates too soon --- higher starting
voltage ==> fewer ADC counts

### Version Log

v3201
First compile of SRAM upgrade firmware v3202
Tied BUS_REGCLR to GND as in master branch v3203
Fix pin mapping in UCF file
v3301
Merge with vFE33 and feature/ramp_settle
- ramp_settle feature not working as anticipated (Wilkinson counter starts too early)

v3401
Merge with vFE34
v3402
Refactor feature/ramp_settle
(delay BUS_CLR and BUS_RD_ENA along with BUS_RAMP)

Now 2nd-window ADC performance is restored! ... but

Latest bit file shows outliers in pedestals from new SRAM (hardware seems okay --- need to investigate further)

### Remaining Tasks

SRAM Expansion PCB
Finalize +5V connector choice
(Cheap, easy, secure, non-interference) Double-check PCB design
(Characteristic impedance? Image-current path? Happy with silkscreen?)
Order 3 more, solder & test, then order production run
Design RTM board for +5V supply Design wire harness
(Determine gauge from power budget, appropriate flexibility or stiffness, how to sheath and preform bends)

Investigate feasibility of securing SRAM PCB with standoff
Enough threads for proper engagement? Necessary screw sizes available to fully utilize threads?
Screw heads don't interfere with neighbor boards?
Investigate SCROD fastening hardware at same time
Same considerations as above
Ease of installation?
Order all hardware, wire spools, and ICs Design clamp tool for easy MB removal

### Timeline

Jan | Feb | Mar | Apr | May | Jun | Jul | Aug | Sep | Oct | Nov | Dec

Soldered 1st board

| Testing
| | Finalize board designs
| | | ------------Production run------------(Send to board fab. house)
| | | Build Wiring Harnesses in house (12 required) | | | ------------Installation------------

# Backup

### Pedestal Outliers


Top: Bus A
Bottom: Bus B (new SRAM)
Streaming pedestal values only (direct from SRAM chips to debug wave FIFO)
Four outliers in this example waveform (typical)
Reverting to previous bitfile fixed issue, so new hardware is not the issue
Firmware logic changes completely unrelated Suspect cross-talk from unconstrained GPIO pins --- will investigate on oscilloscope

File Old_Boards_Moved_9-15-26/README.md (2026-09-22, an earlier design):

# Old_Boards_Moved_9-15-26

**State:** boards at tag `pre-matt-review` (68cfe44): single RTM fuse, fanout without fuses, SRAM C1/C2 0402, old serial block.
**Superseded on:** 2026-09-15 by Matt's first review (4 RTM fuses, IDL silkscreen line, 0.4 mm 3.3 V zone clearance).
**Use:** reference only — current files are in `../Finalized-Boards/`.

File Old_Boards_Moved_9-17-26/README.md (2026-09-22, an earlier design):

# Old_Boards_Moved_9-17-26

**State:** Matt's first review and the 9/16 follow-up applied (4 RTM fuses in a row, IDL_26_026 line, 0.4 mm zone clearance); tag `pre-matt-review-2`.
**Superseded on:** 2026-09-17 by paired RTM 5V/GND terminals, SRAM R1/R2 to 0603, and per-destination fanout fuses.
**Use:** reference only — current files are in `../Finalized-Boards/`.

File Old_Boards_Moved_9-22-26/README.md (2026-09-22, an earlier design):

# Old_Boards_Moved_9-22-26

**State:** 9/17 layout (paired RTM terminals, R1/R2 0603, fanout fuses) with the lab-stock 1.1 A polyswitch MF-MSMF110/16-2 on RTM F1–F4 and fanout F1–F4; tag `polyswitch-1.1A`.
**Superseded on:** 2026-09-22 by sized polyswitches — RTM MF-MSMF030-2 (0.3 A hold), fanout MF-MSMF010-2 (0.1 A hold).
**Use:** reference only — current files are in `../Finalized-Boards/`. Use this folder (or `git checkout polyswitch-1.1A`) if the boards are built with the stock 1.1 A parts.
**Differs from current only in the F1–F4 Value field** on both boards — same 1812 footprint, no layout change.

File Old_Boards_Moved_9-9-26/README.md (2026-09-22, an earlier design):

# Old_Boards_Moved_9-9-26

**State:** Chris Ketter's three boards (SRAM card, RTM +5 V, 2-pole fanout) as received, before any of Robbie's edits.
**Superseded on:** 2026-09-09 by the SMD-fuse RTM/fanout variants and the first SRAM edits.
**Use:** reference only — current files are in `../Finalized-Boards/`.

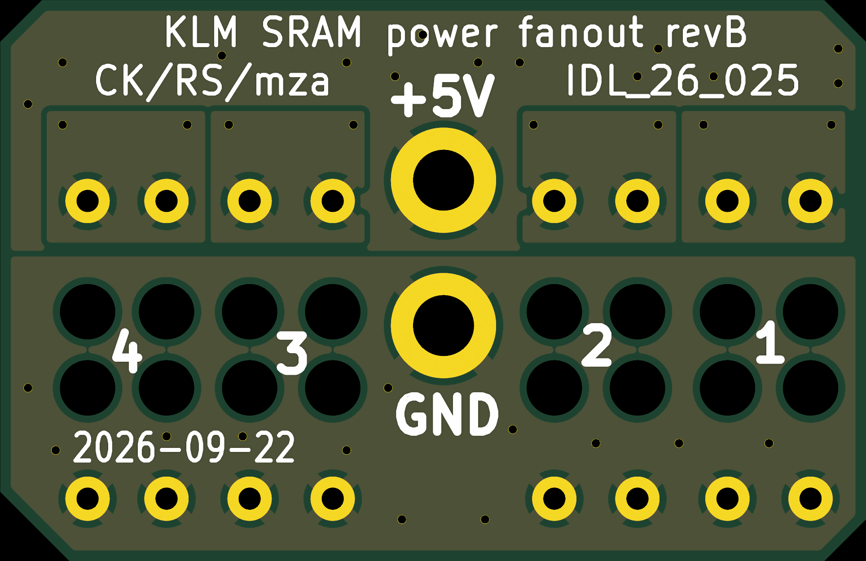
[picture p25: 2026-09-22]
Finalized-Renders/fanout_smd_bottom.png

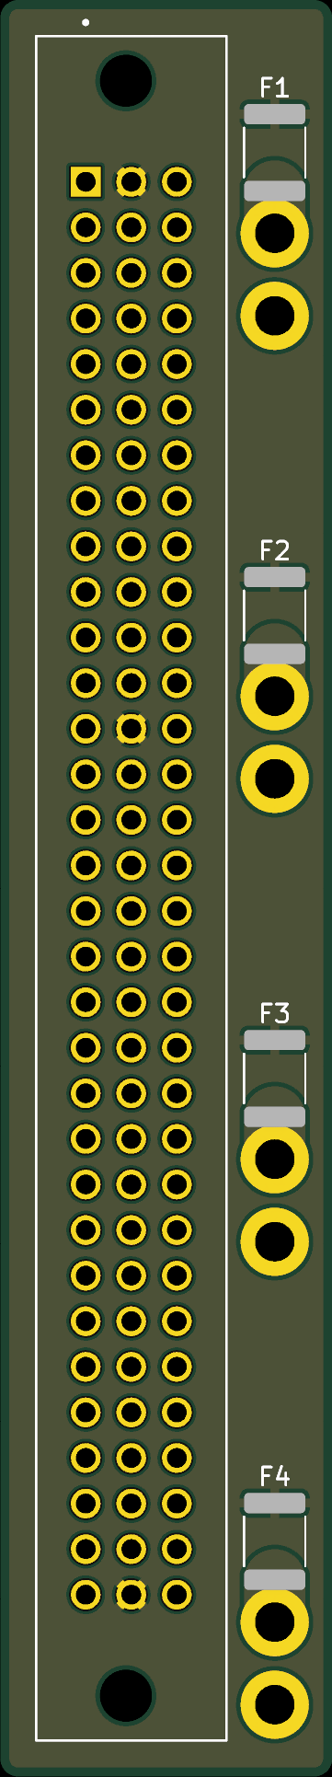
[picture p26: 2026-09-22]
Finalized-Renders/rtm_smd_top.png

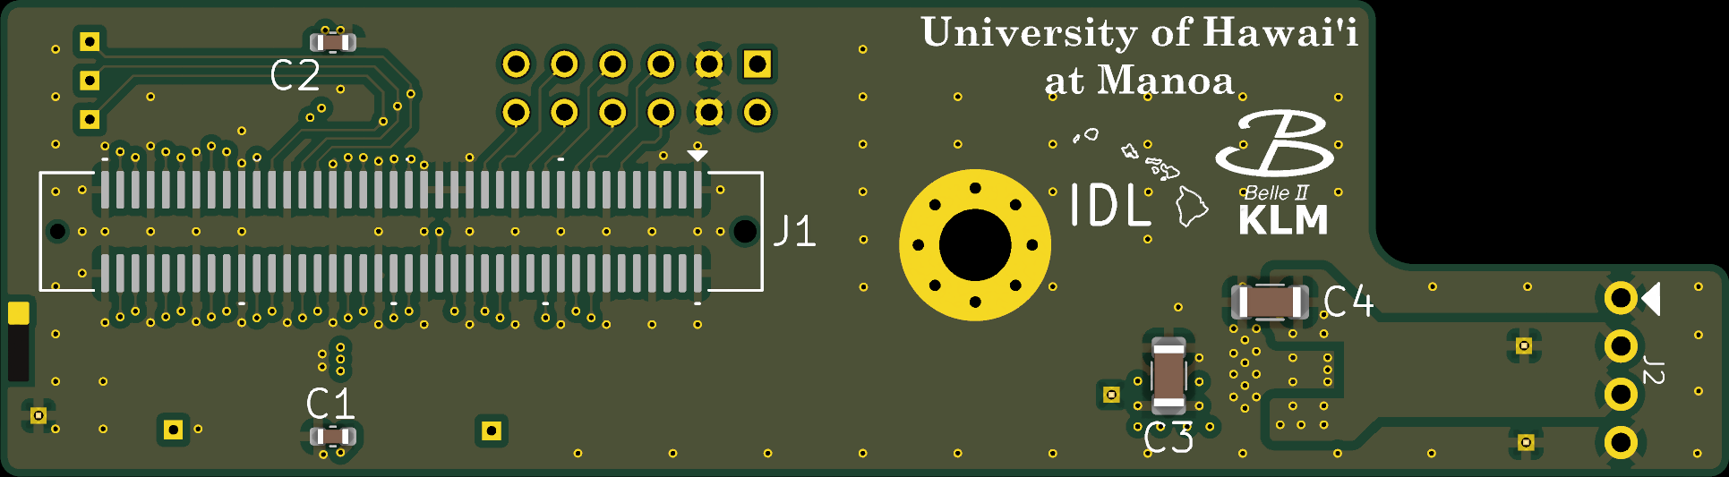
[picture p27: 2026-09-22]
Finalized-Renders/sram_bottom.png

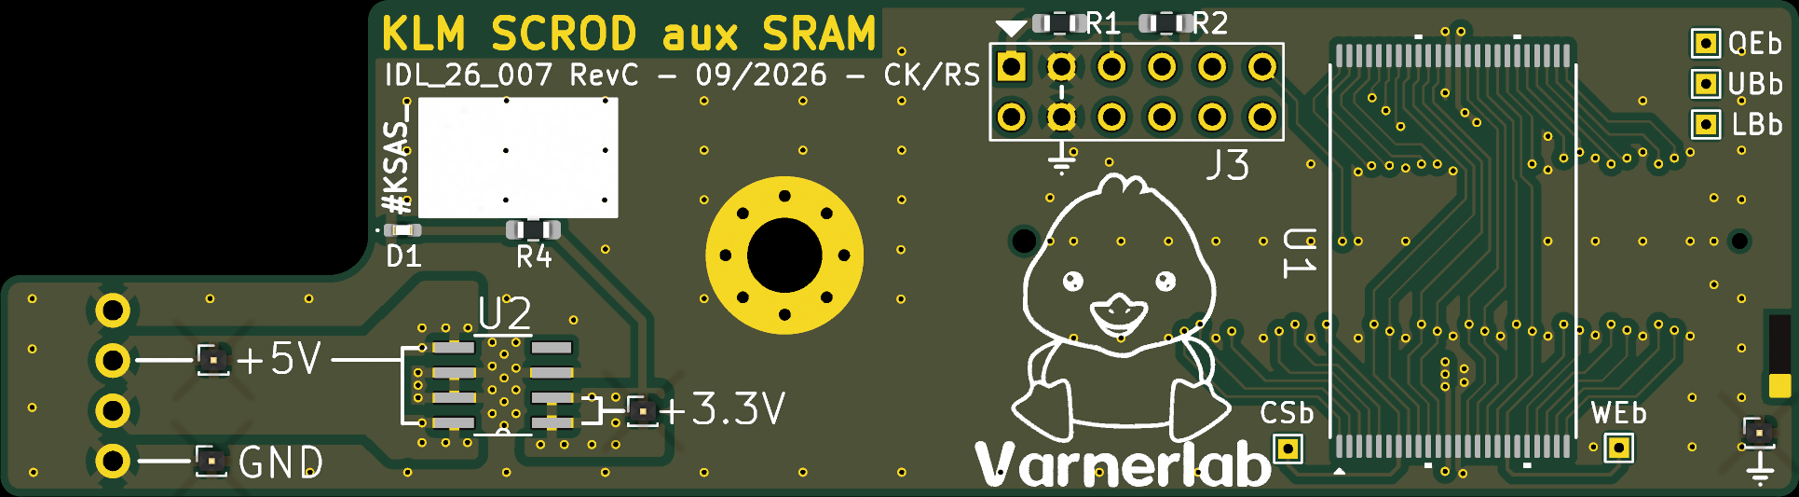
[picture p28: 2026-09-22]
Finalized-Renders/sram_top.png

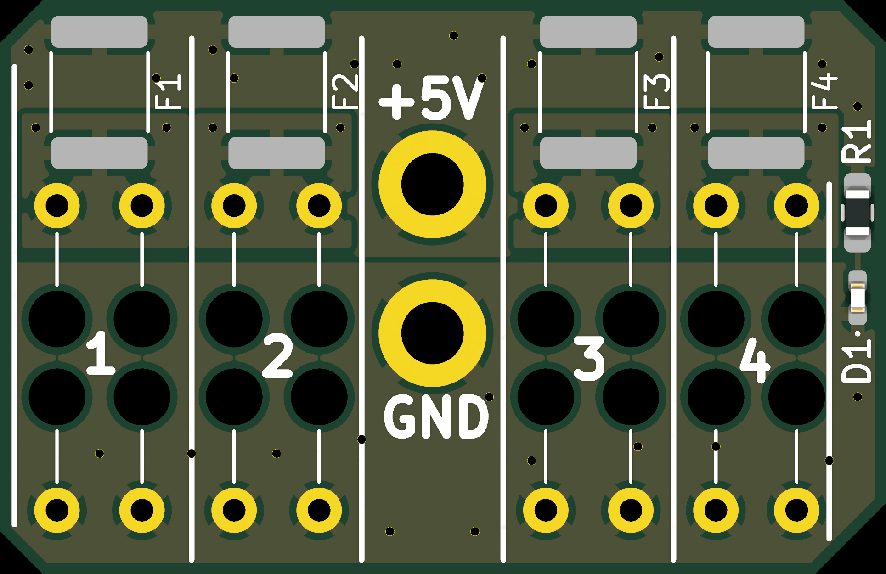
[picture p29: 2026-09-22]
Finalized-Renders/fanout_smd_top.png

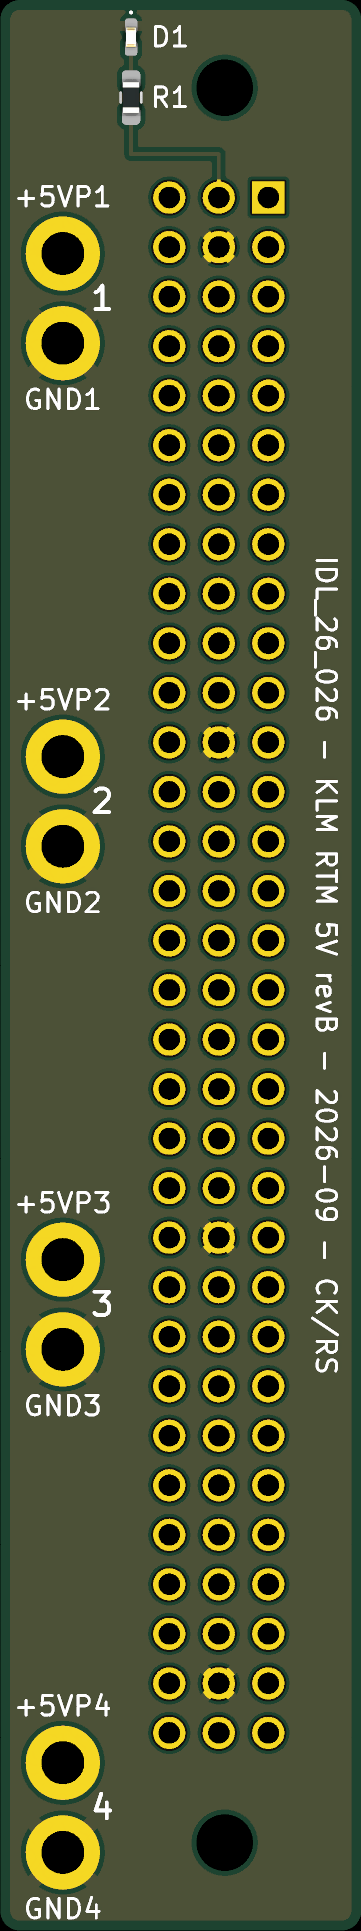
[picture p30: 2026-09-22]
Finalized-Renders/rtm_smd_bottom.png

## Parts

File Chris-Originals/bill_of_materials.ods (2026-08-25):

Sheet: Cost est.
 |  |  |  |  |  |  |  |  |  |  |  | notes
N SRAM Expansion Boards: |  |  | SRAM Expansion Board:
Required | 20% spare | Total | Item | Description | Part Number | Quantity | Unit Price | Sub Totals | Order | Actual | Stock
136 | 28 | 164 | 1 | SRAM chips | 706-1467-ND (https://www.digikey.com/en/products/detail/issi-integrated-silicon-solution-inc/IS61WV204816BLL-10TLI/6004263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) | 164 | $19.49 | $3,196.99 | TRUE | $3,196.99 | 2
Size (sq. in.) |  |  | 2 | regulator | LT1963AES8-3.3#TRPBF (https://www.digikey.com/en/products/detail/analog-devices-inc/LT1963AES8-3-3-TRPBF/958755) | 164 | $3.75 | $615.00 | 31 | $116.25 | 133
4 |  |  | 3 | CONN HEADER R/A 4POS 2.54MM | WM4302-ND (https://www.digikey.com/en/products/detail/molex/0022053041/26693?s=N4IgTCBcDaIOoFkAsBmADGAtAOQCIgF0BfIA) | 164 | $0.22 | $36.08 | TRUE | $36.08 |  | 4-pin molex 2.54mm pitch
$ / sq. in (prototype) |  |  | 4 | Mezzanine Connectors | A99191CT-ND (https://www.digikey.com/en/products/detail/te-connectivity-amp-connectors/5177985-3/1893951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) | 164 | $4.17 | $683.88 | FALSE | $0.00 | 241 | 80 pin
10 |  |  | 5 | CAP CER 100UF 10V X5R 1206 | 445-6007-6-ND (https://www.digikey.com/en/products/detail/tdk/C3216X5R1A107M160AC/2443485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) | 328 | $0.49 | $161.97 | TRUE | $161.97 | plenty
$ / sq. in (100 in^2 min, mult. of 10) |  |  | 6 | CAP CER 10UF 10V X5R 0402 | 490-GRM155R61A106ME11DDKR-ND (https://www.digikey.com/en/products/detail/murata-electronics/GRM155R61A106ME11D/12091056) | 1,000 | $0.01 | $13.00 | TRUE | $13.00
2 |  |  | 7 | Al standoffs | https://www.mcmaster.com/93330A470 | 164 | $0.30 | $49.20 | TRUE | $49.20
 |  |  | 8 | box 100 18-8 Btn. Hd. hex screws | https://www.mcmaster.com/92949A141 | 4 | $4.47 | $17.88 | TRUE | $17.88
 |  |  | 9 | PCB Fabrication | OSH-PARK 4-layer | 164 | $8.00 | $1,312.00 | TRUE | $1,312.00
 |  |  | 10 | Assembly | PCBWay.com ? (http://pcbway.com/?) | 164 | $3.33 | $546.67 | TRUE | $546.67
 |  |  |  | Total |  |  |  | $6,632.66 |  | $5,450.03
N Power Distribution Boards: |  |  | Power Distribution Board:
Required | 20% spare | Total | Item | Description | Part Number | Quantity | Unit Price | Sub Totals | Order | Actual | Stock
12 | 3 | 15 | 1 | CONN DIN RCPT 96POS | 1195-1197-ND (https://www.digikey.com/en/products/detail/harting/09032966825/3179780) | 15 | $3.58 | $53.64 | FALSE | $0.00 | plenty | 96 pin
Size (sq. in.) |  |  | 2 | FUSE BLOCK BLADE 500V 20A PCB | 36-3544-2-ND (https://www.digikey.com/en/products/detail/keystone-electronics/3544-2/316029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) | 15 | $0.83 | $12.45 | TRUE | $12.45
3 |  |  | 3 | PCB Fabrication | OSH-PARK 4-layer | 15 | $6.00 | $90.00 | TRUE | $90.00
 |  |  |  | Total |  |  |  | $156.09 |  | $102.45
 |  |  | Wiring Harness
Length heavy gauge (cm) | (ft) | Total (ft) | Item | Description | Part Number | Quantity | Unit Price | Sub Totals | Order | Actual | Stock
120 | 3.9 | 59 | 1 | Multi-Conductor Cables 12AWG 2C SHIELD 500ft SPOOL GRAY | 5000FE 008500 (https://www.mouser.com/ProductDetail/Belden-Wire-Cable/5000FE-008500?qs=U1cgCdF9Le9STC5iq7G2tQ%3D%3D) | 1 | ??? | $0.00 | FALSE | $0.00 | plenty
 |  |  | 2 | EXPAND SLEEVING 1/8" X 225' BLK | 1030-PTN0.13BK225-ND (https://www.digikey.com/en/products/detail/techflex/PTN0-13BK225/2502446) | 1 | $44.14 | $44.14 | TRUE | $44.14
Length Sheathing (cm) | (ft) |  | 3 | HEATSHRINK FP301 1/4" BLACK | FP014K-200-ND (https://www.digikey.com/en/products/detail/3m/FP-301-1-4-BL-200/116675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) | 200 | $0.58 | $116.28 | TRUE | $116.28
30.48 | 1.0 | 164 | 4 | COMPACT SPLICING CONNECTOR BULK | 2946-221-613-ND (https://www.digikey.com/en/products/detail/wago-corporation/221-613/13619780) | 11 | $1.07 | $11.79 | TRUE | $11.79
 |  |  | 5 | SPLICE LEVER 10-20AWG 5POS | 2946-221-615-ND (https://www.digikey.com/en/products/detail/wago-corporation/221-615/13619777) | 20 | $1.68 | $33.66 | TRUE | $33.66
TO DO: |  |  | 6 | PCB - power fanout | OSH-PARK 4-layer | 42 | $2.00 | $84.00 | TRUE | $84.00
Work out total area of all board designs to determine cost --- must order all together to ensure benefit of four-layer medium service run at $2 per sq. in. Regardless of price estimation, production batch should be ordered with all boards together. |  |  | 7 | CONN RCPT HSG 4POS 2.54MM | WM2002-ND (https://www.digikey.com/en/products/detail/molex/0022013047/26435) | 164 | $0.12 | $19.68 | TRUE | $19.68 |  | 4-pin molex 2.54mm pitch
 |  |  | 8 | 12" PRE-CRIMP A2016 BLACK | 0008500113-12-B2-ND (https://www.digikey.com/en/products/detail/molex/0008500113-12-B2/5987703) | 328 | $0.56 | $182.67 | TRUE | $182.67
 |  |  | 9 | 12" PRE-CRIMP A2016 WHITE | 0008500113-12-W2 (https://www.digikey.com/en/products/detail/molex/0008500113-12-W2/5987743) | 328 | $0.56 | $182.67 | TRUE | $182.67
 |  |  | 10 | TAPE ELECTRIC PRINT BK 3/4"X22YD | 3M158586-ND (https://www.digikey.com/en/products/detail/3m/1700P-PRINTED-3-4X66/7674711) | 4 | $5.16 | $20.64 | TRUE | $20.64
 |  |  |  | Total |  |  |  | $695.53 |  | $695.53
 |  |  | SCROD support hardware:
 |  |  | Item | Description | Part Number | Quantity | Unit Price | Sub Totals | Order | Actual
 |  |  | 1 | Standoffs | https://www.mcmaster.com/93330A443 | 328 | 0.36 | $118.08 | TRUE | $118.08
 |  |  | 2 | Button-head cap screws | https://www.mcmaster.com/92949A143 | 7 | 5.04 | $35.28 | TRUE | $35.28
 |  |  |  | Total |  |  |  | $153.36 |  | $153.36
 |  |  | Grand Total |  |  |  |  | $7,637.65 |  | $6,401.38
 |  |  | Misc.
 |  |  | Item | Description | Part Number | Quantity | Unit Price | Sub Totals
 |  |  | 1 | 2 Prototype stages |  | 2 | $246.85 | $493.70 |  |  |  | $10/sq.in., min 3x/order
 |  |  | 2 | Shipping* |  | 1 | $150.00 | $150.00
 |  |  | 3 | Lab Supplies** |  | 1 | $250.00 | $250.00
 |  |  |  | Grand total | Grand total |  |  | $7,835.81
*Shipping includes acquiring parts from digikey or others, and it includes sending the boards to a fabrication house if we go that route.
**Lab supplies includes, solder, solder tips, gloves, masks, isopropanol, restocking capacitors and resistors as needed, etc.
***Tarriffs may apply

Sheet: MB gerb. dim.
KLM_TX_9U_MB RevC gerber file dimensions for layout of KLM_Scint_SRAM_exp
Feature | x | y | new x | new y
MB front edge | 25.4 |  | 100
MH1 | 57.5234 | 284.1752 | 132.1234 | 115.0001
MH2 | 118.4834 | 284.1752 | 193.0834 | 115.0001
boss1 | 69.6417 | 284.8915 | 144.2417 | 114.2838
boss2 | 105.8418 | 284.8915 | 180.4418 | 114.2838
top silkscreen |  | 299.1753 |  | 100
right silkscreen | 123.7244 |  | 198.3244
top Al. bracket loc |  | 269.01 |  | 130.1653
New origin | -74.6 | 399.1753
(x0 = MB front edge - 100, y0 = top silkscreen + 100, y-direction inverted)
board top-left |  |  | 100 | 100
board bot-right |  |  | 198.3244 | 128.9653

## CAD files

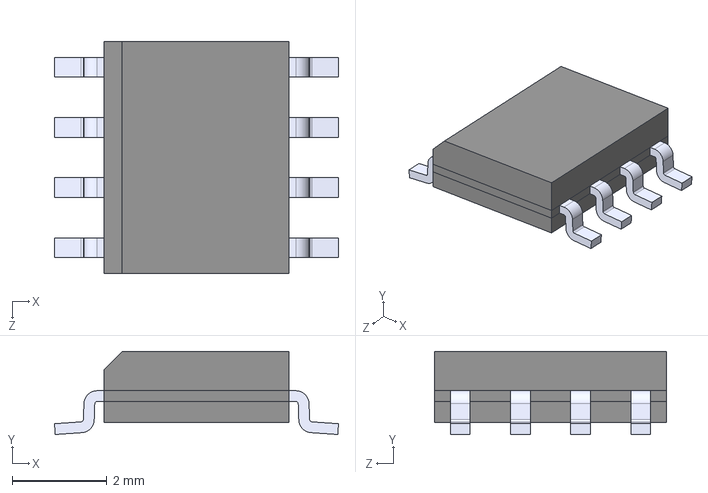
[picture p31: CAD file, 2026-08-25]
Chris-Originals/kicad_lib/cad_lib/LT1963AES8-3.3PBF.step
5.99 x 1.75 x 4.90 mm

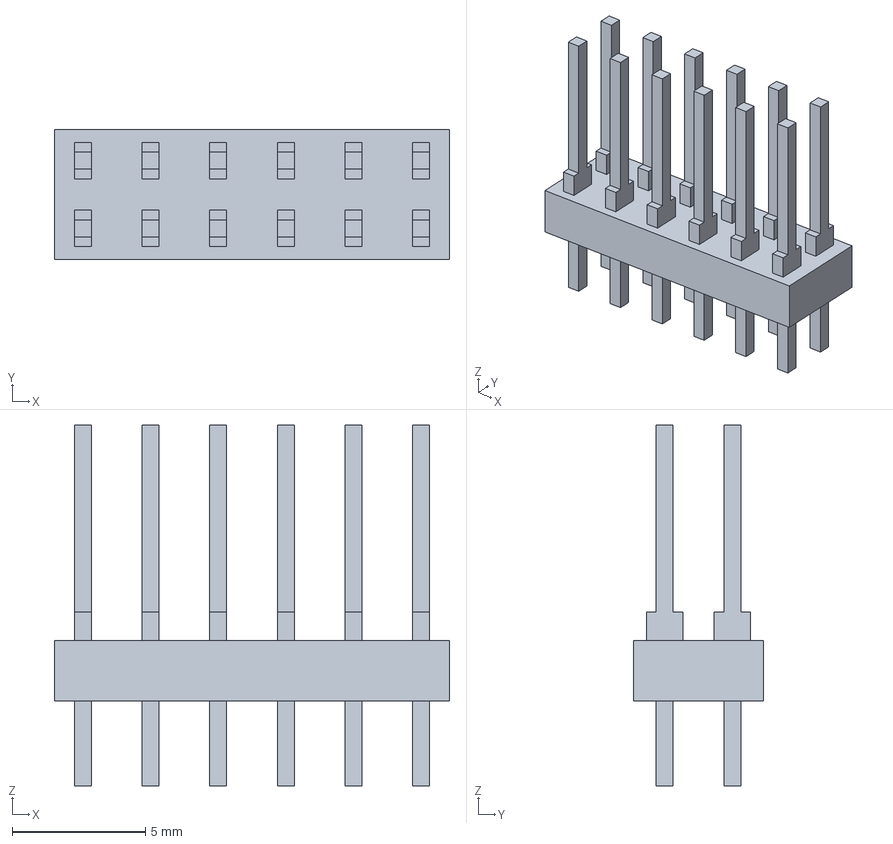
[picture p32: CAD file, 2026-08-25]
Finalized-Boards/kicad_lib/cad_lib/CONN_HEADER_VERT_12POS_2.54MM.step
14.8 x 4.88 x 13.5 mm

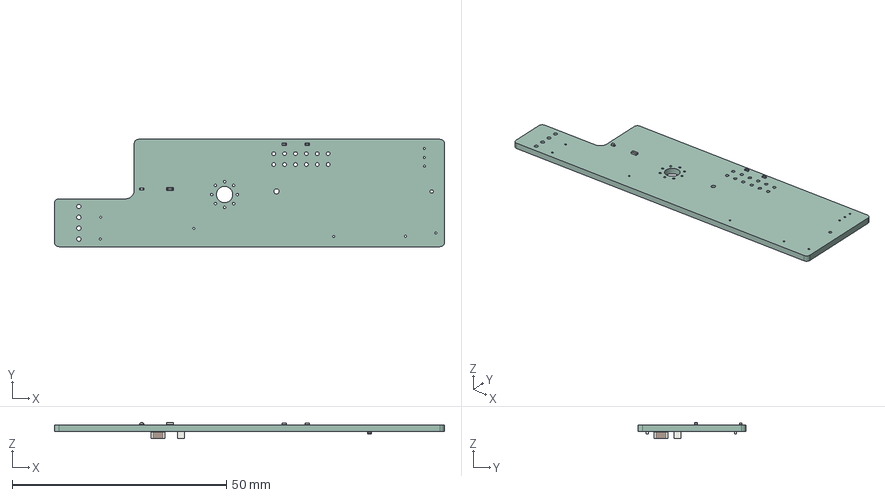
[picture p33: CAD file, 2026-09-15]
Finalized-Boards/KLM_aux_SRAM/SRAM.step
91.0 x 25.1 x 3.78 mm
R_0402_1005Metric x 2
R_0603_1608Metric
LED_0402_1005Metric
C_1206_3216Metric x 2
C_0402_1005Metric x 2
SRAM_exp_PCB

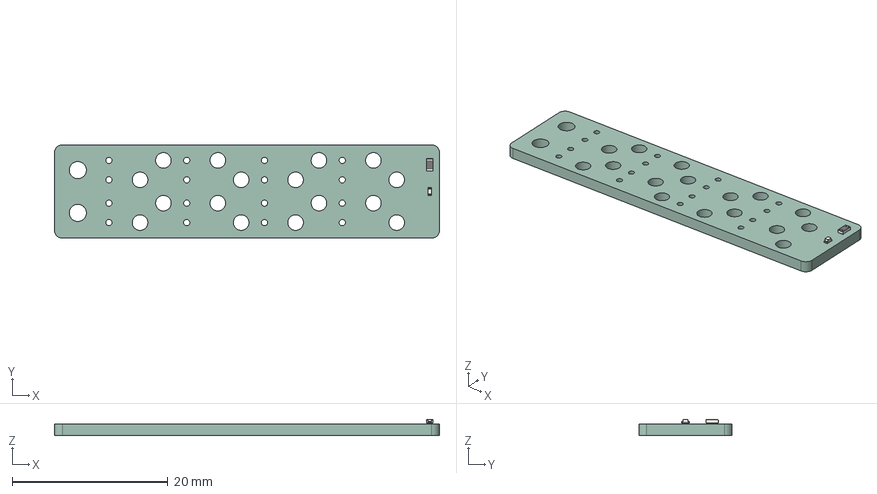
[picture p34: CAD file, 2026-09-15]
Finalized-Boards/one2eight_twoPole/fanout.step
49.5 x 12.0 x 2.09 mm
LED_0402_1005Metric
R_0603_1608Metric
one2eight_twoPole_SMD_PCB

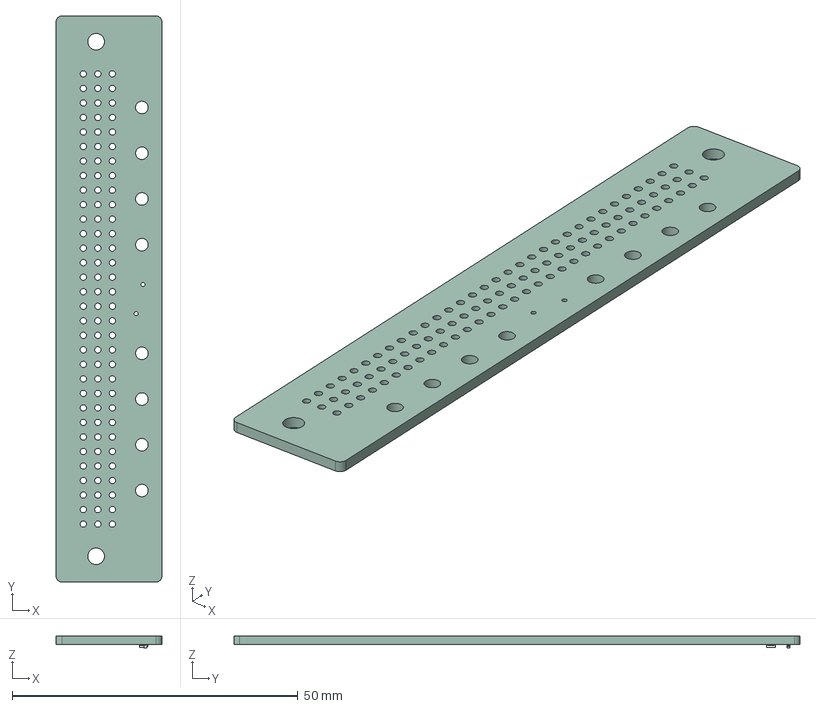
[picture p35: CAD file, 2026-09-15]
Finalized-Boards/RTM_5V_supply/RTM.step
18.5 x 99.0 x 2.09 mm
LED_0402_1005Metric
R_0603_1608Metric
RTM_5V_supply_SMD_PCB

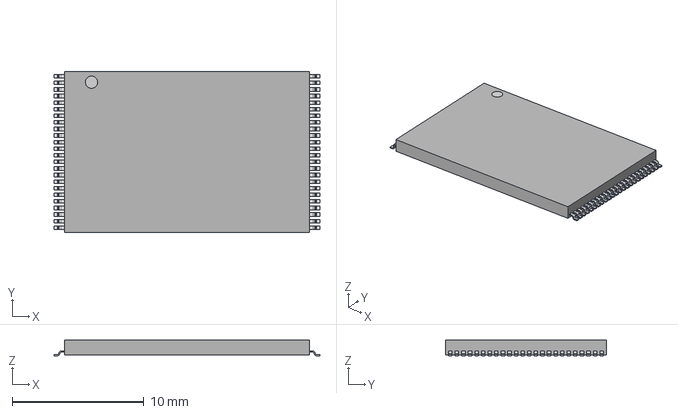
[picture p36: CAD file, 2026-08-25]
Chris-Originals/kicad_lib/cad_lib/48L_TSOP-1_12X20_ISI.step
20.2 x 12.2 x 1.20 mm

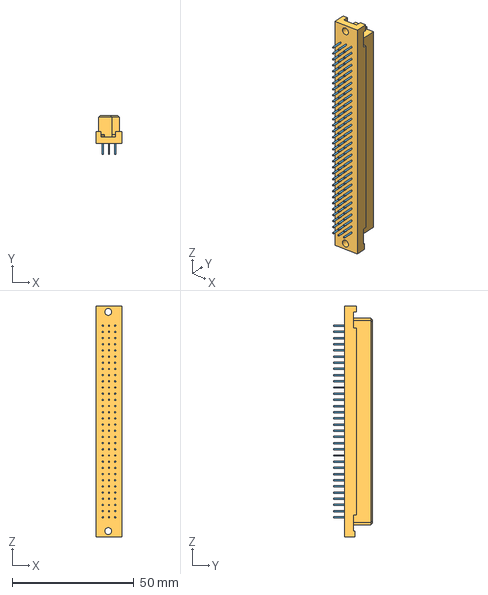
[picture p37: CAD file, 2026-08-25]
Chris-Originals/kicad_lib/cad_lib/CONN_DIN_RCPT_96POS.STP
10.5 x 16.1 x 94.9 mm

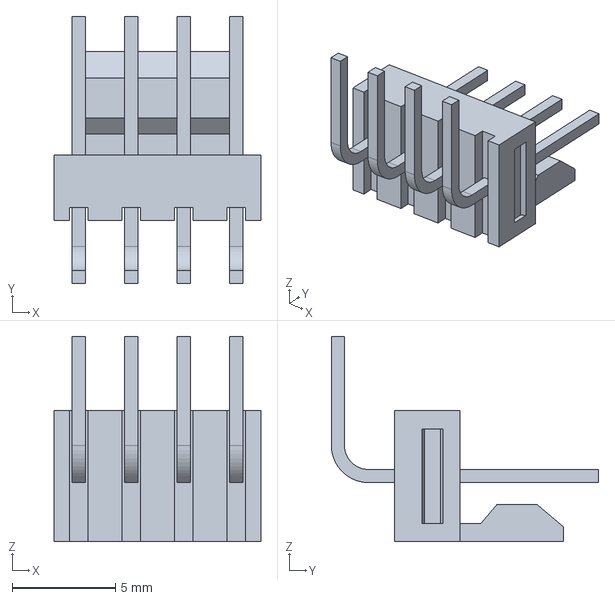
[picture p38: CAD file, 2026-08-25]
Finalized-Boards/kicad_lib/cad_lib/molex_conn_ra_4pos_022053041.stp
10.0 x 12.9 x 9.93 mm

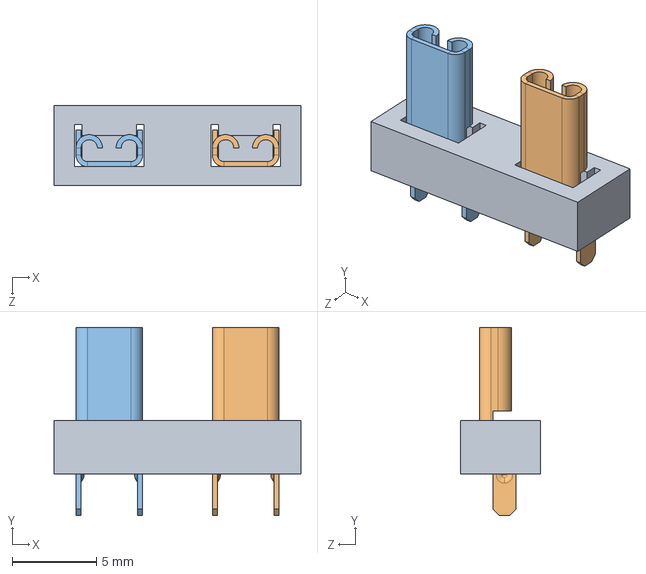
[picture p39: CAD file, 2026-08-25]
Chris-Originals/kicad_lib/cad_lib/3544-2.step
14.7 x 11.2 x 4.75 mm

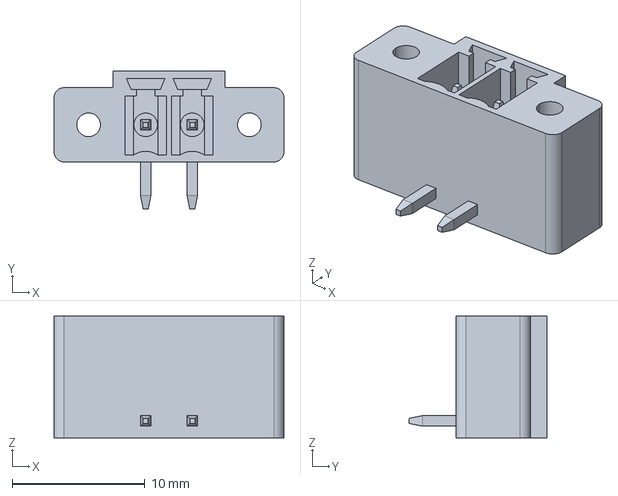
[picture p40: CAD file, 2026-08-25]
Chris-Originals/kicad_lib/cad_lib/molex_term_block_eurostyle_RA_2pos_male_through_hole_3p5mm.stp
17.3 x 10.4 x 9.14 mm

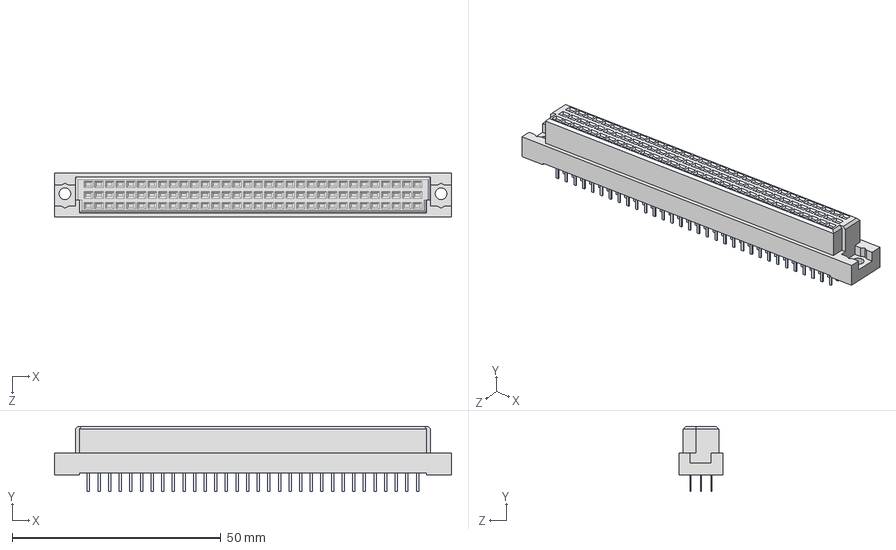
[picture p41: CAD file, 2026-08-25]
Finalized-Boards/kicad_lib/cad_lib/AMPHENOL_CONN_DIN_RCPT_96POS.step
95.0 x 15.6 x 10.5 mm

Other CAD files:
Chris-Originals/kicad_lib/cad_lib/A99191CT-ND__CONN_RCPT_80POS_0P8MM.stp
Chris-Originals/kicad_lib/cad_lib/CON8_2X4_TU_TSW_SAI.step
Finalized-Boards/KLM_aux_SRAM/SRAM/C_0402_1005Metric.iam
Finalized-Boards/KLM_aux_SRAM/SRAM/C_0402_1005Metric.ipt
Finalized-Boards/KLM_aux_SRAM/SRAM/C_1206_3216Metric.iam
Finalized-Boards/KLM_aux_SRAM/SRAM/C_1206_3216Metric.ipt
Finalized-Boards/KLM_aux_SRAM/SRAM/LED_0402_1005Metric.iam
Finalized-Boards/KLM_aux_SRAM/SRAM/LED_0402_1005Metric.ipt
Finalized-Boards/KLM_aux_SRAM/SRAM/R_0402_1005Metric.iam
Finalized-Boards/KLM_aux_SRAM/SRAM/R_0402_1005Metric.ipt
Finalized-Boards/KLM_aux_SRAM/SRAM/R_0603_1608Metric.iam
Finalized-Boards/KLM_aux_SRAM/SRAM/R_0603_1608Metric.ipt
Finalized-Boards/KLM_aux_SRAM/SRAM/SRAM.iam
Finalized-Boards/KLM_aux_SRAM/SRAM/SRAM_exp_PCB.ipt
Finalized-Boards/RTM_5V_supply/RTM/LED_0402_1005Metric.iam
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

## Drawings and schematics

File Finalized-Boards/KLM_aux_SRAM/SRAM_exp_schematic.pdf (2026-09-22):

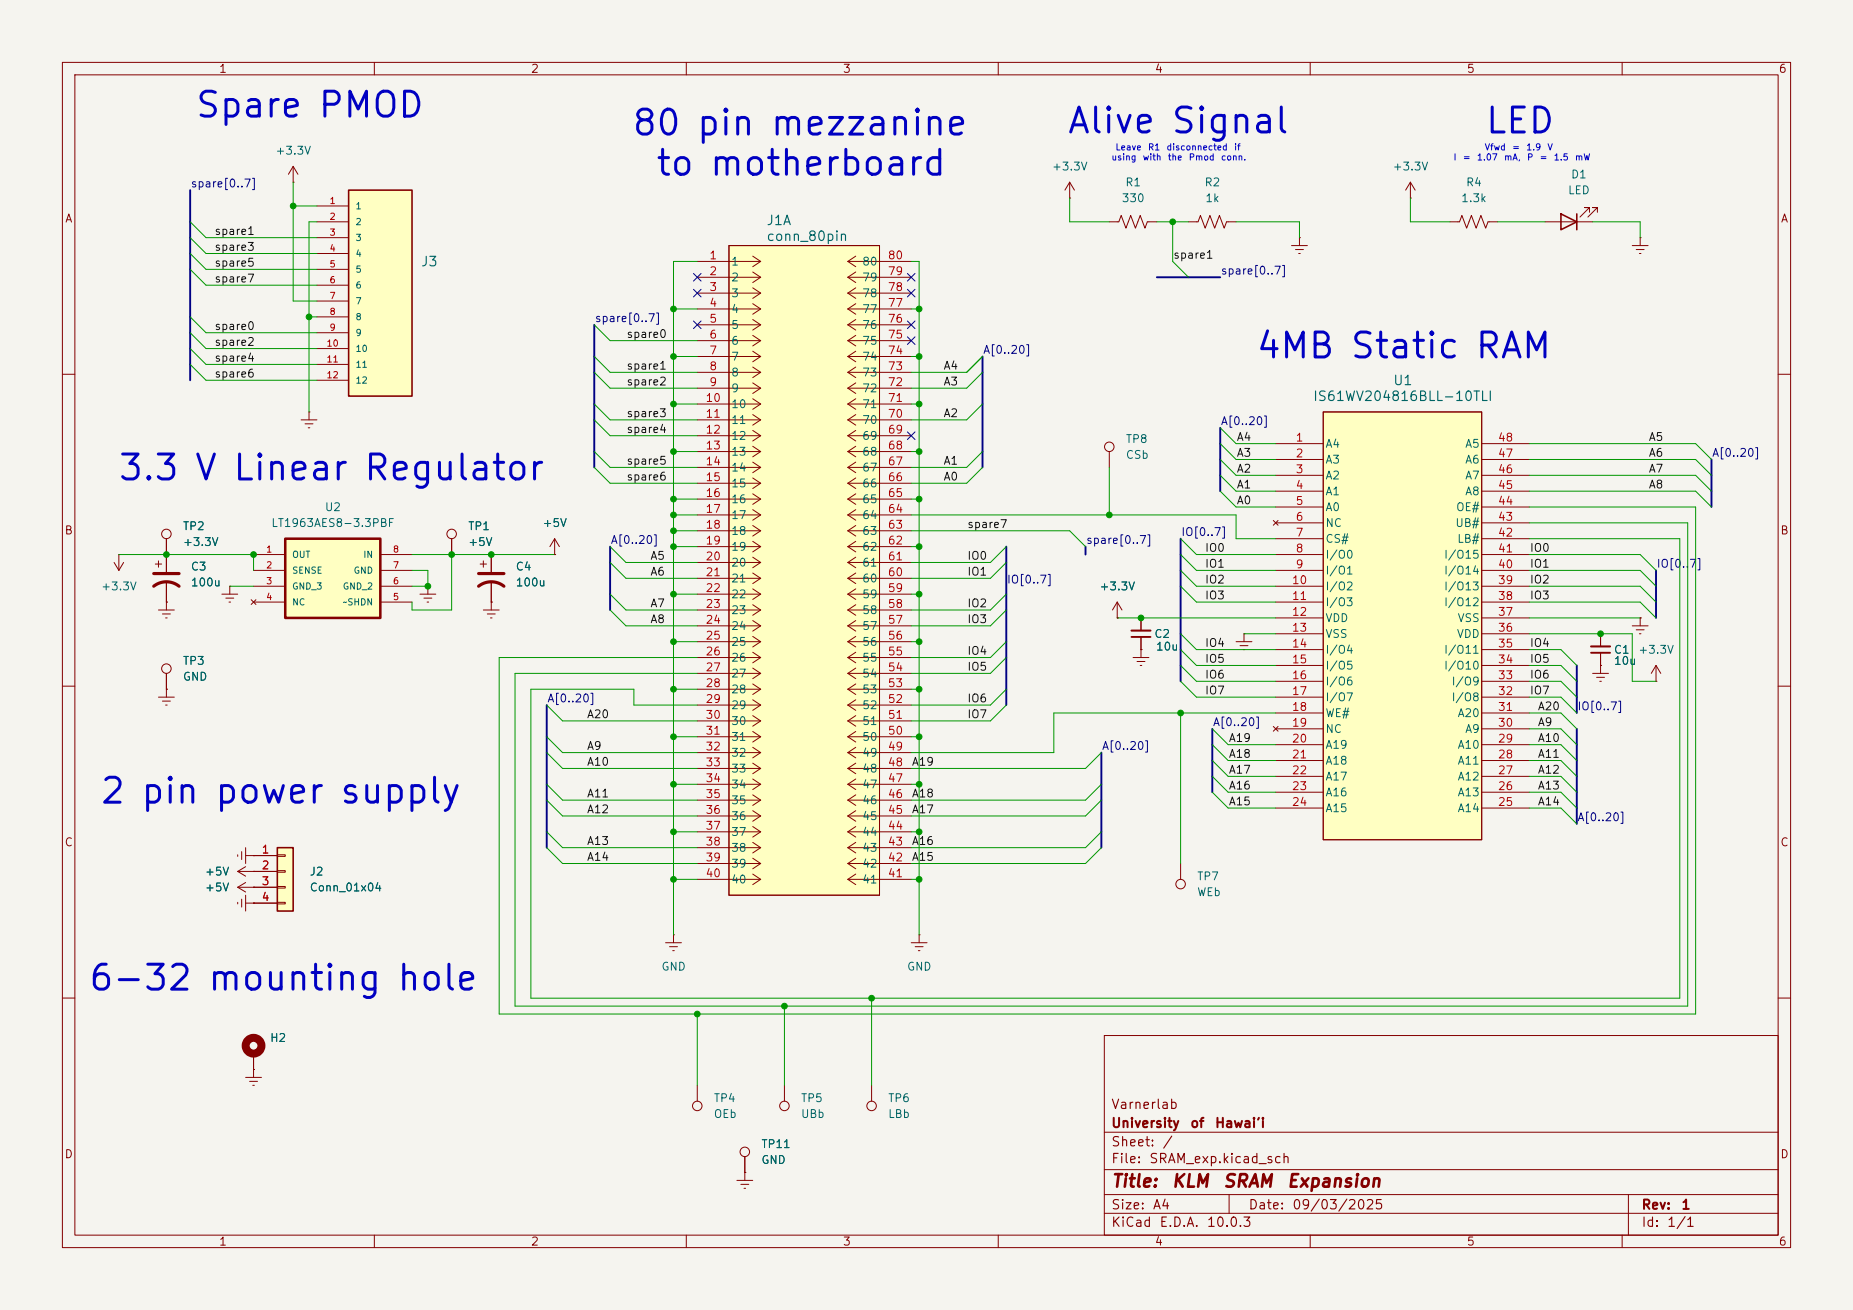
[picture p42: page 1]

University of Hawai'i
Sheet: /
File: SRAM_exp.kicad_sch
Title: KLM SRAM Expansion

Size: A4 | Rev: 1
KiCad E.D.A. 10.0.3 | Id: 1/1

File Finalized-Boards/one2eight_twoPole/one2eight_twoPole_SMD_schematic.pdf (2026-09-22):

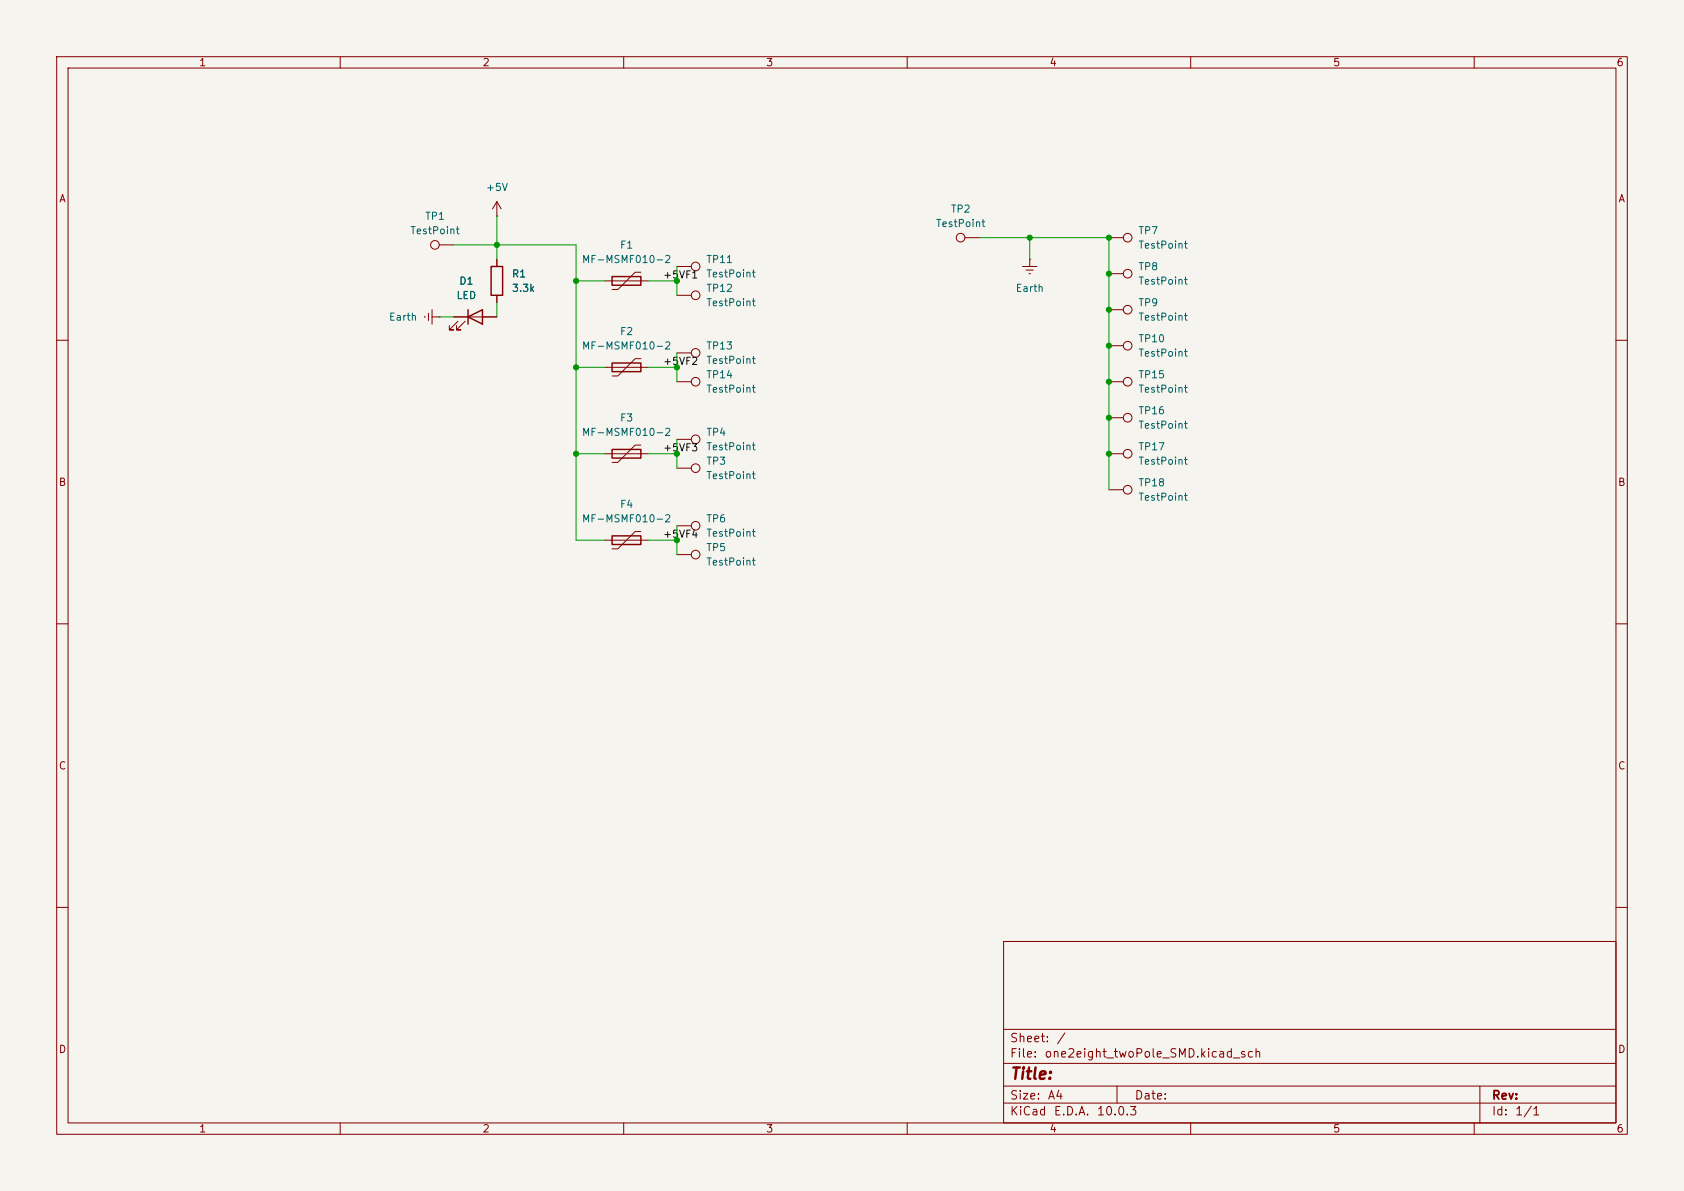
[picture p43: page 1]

Size: A4 | Rev:
KiCad E.D.A. 10.0.3 | Id: 1/1

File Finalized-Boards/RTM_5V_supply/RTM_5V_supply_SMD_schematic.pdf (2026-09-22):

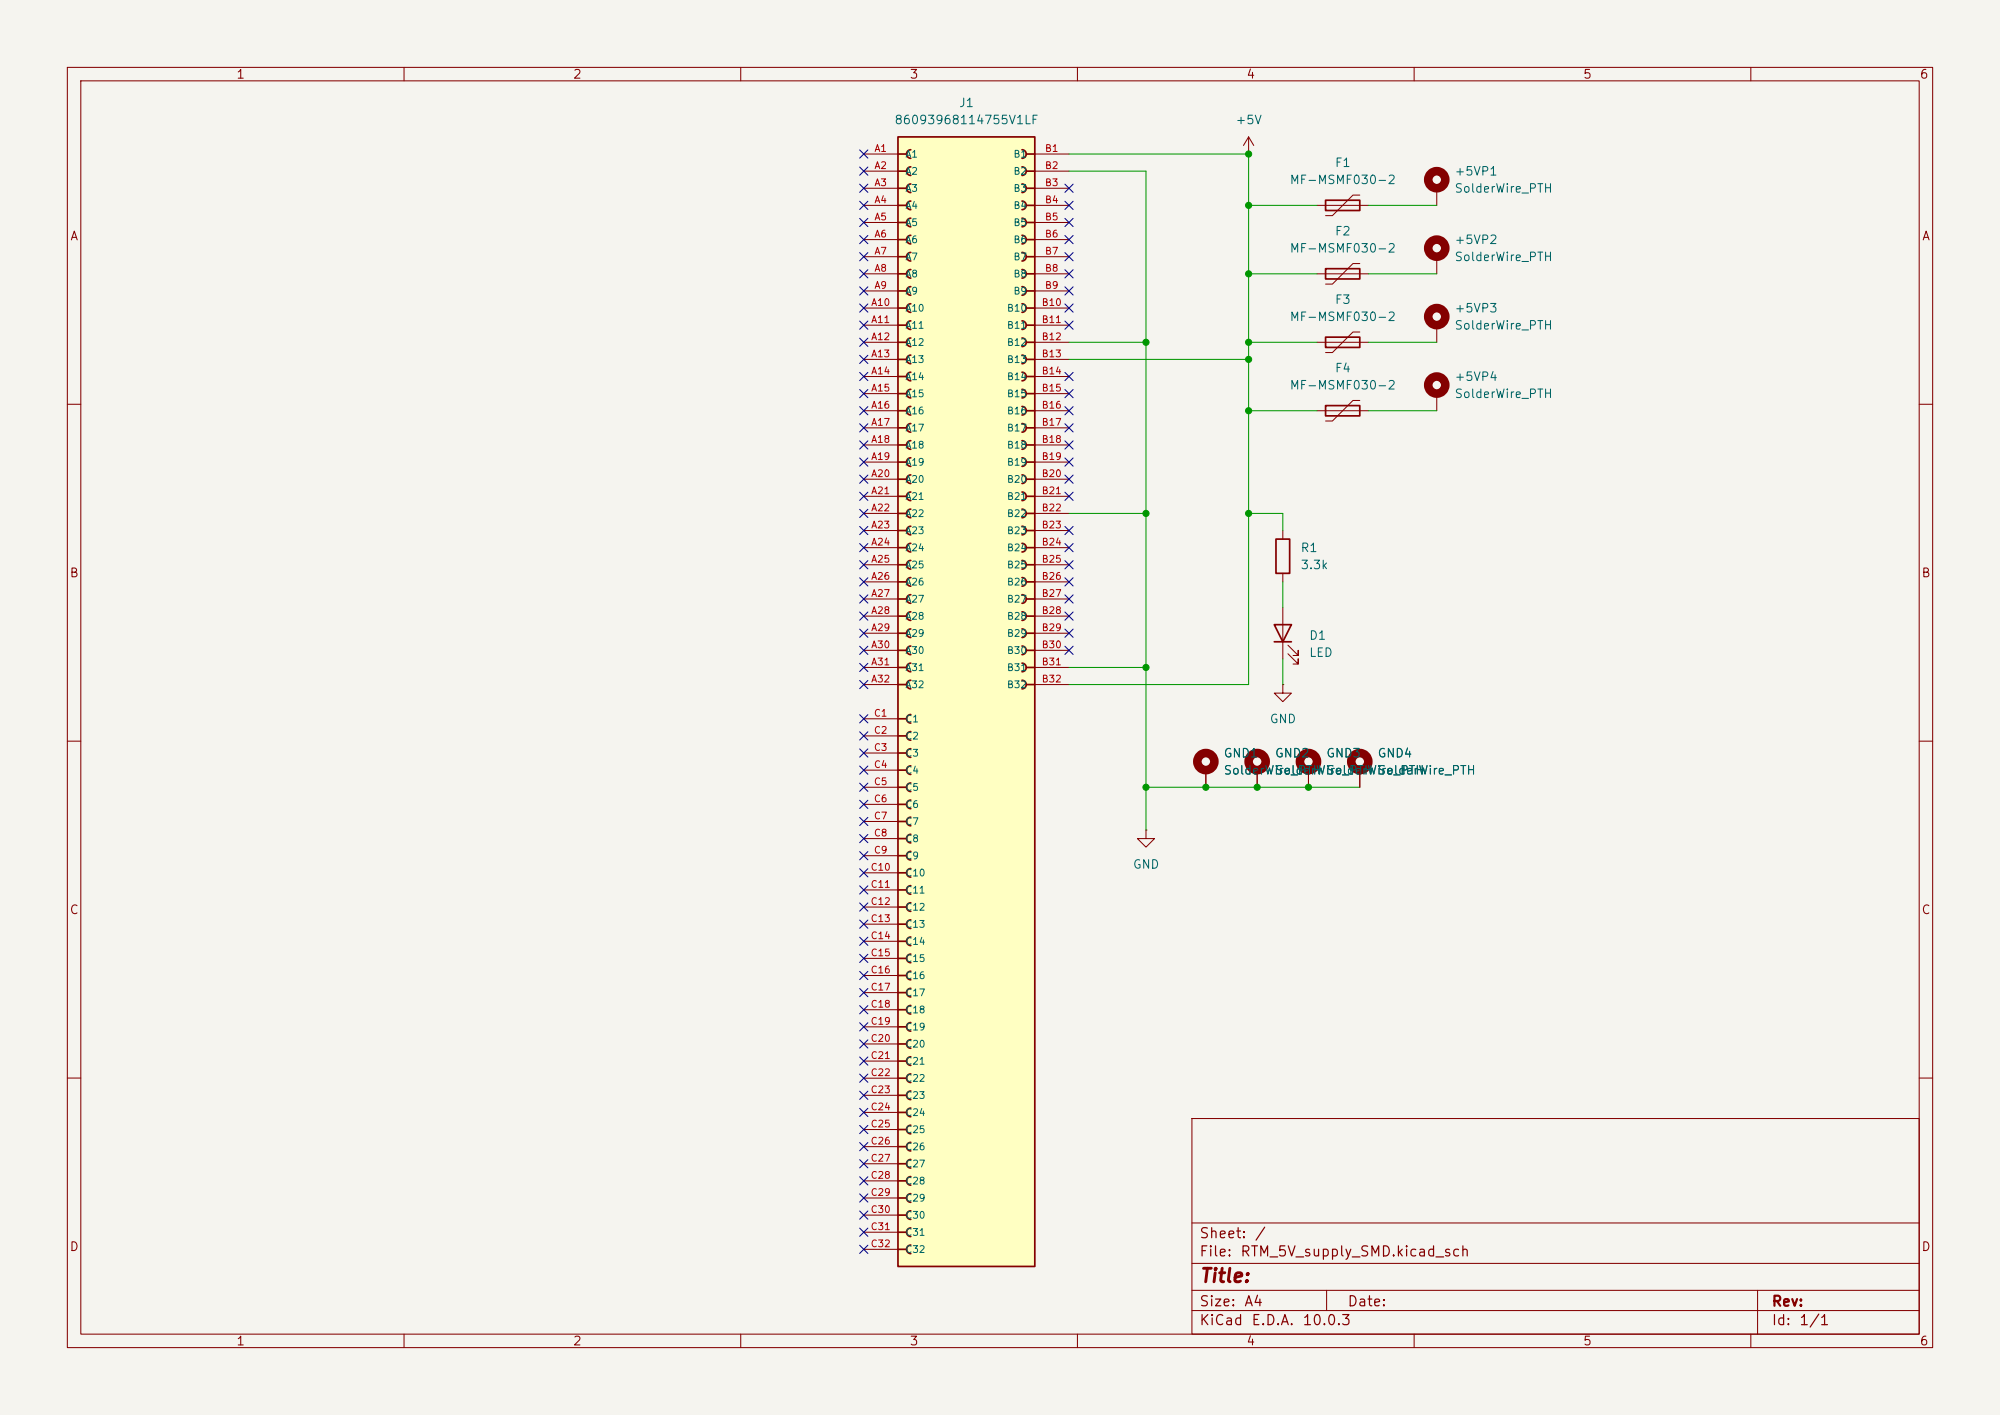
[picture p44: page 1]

Size: A4 | Rev:
KiCad E.D.A. 10.0.3 | Id: 1/1

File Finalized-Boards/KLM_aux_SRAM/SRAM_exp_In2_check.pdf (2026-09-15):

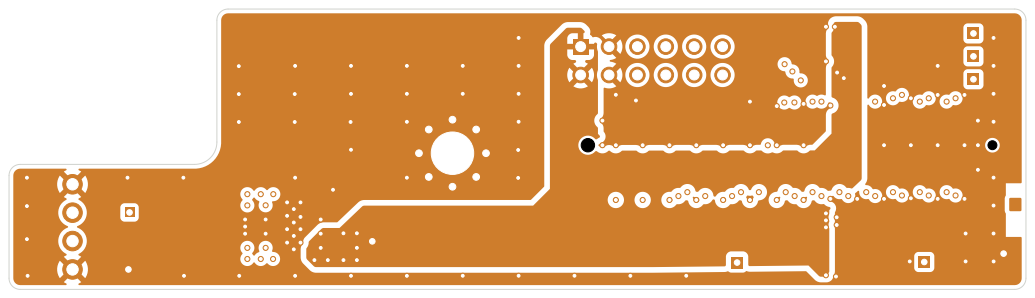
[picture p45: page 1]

Size: A4 | Rev:
KiCad E.D.A. 10.0.6 | Id: 1/1

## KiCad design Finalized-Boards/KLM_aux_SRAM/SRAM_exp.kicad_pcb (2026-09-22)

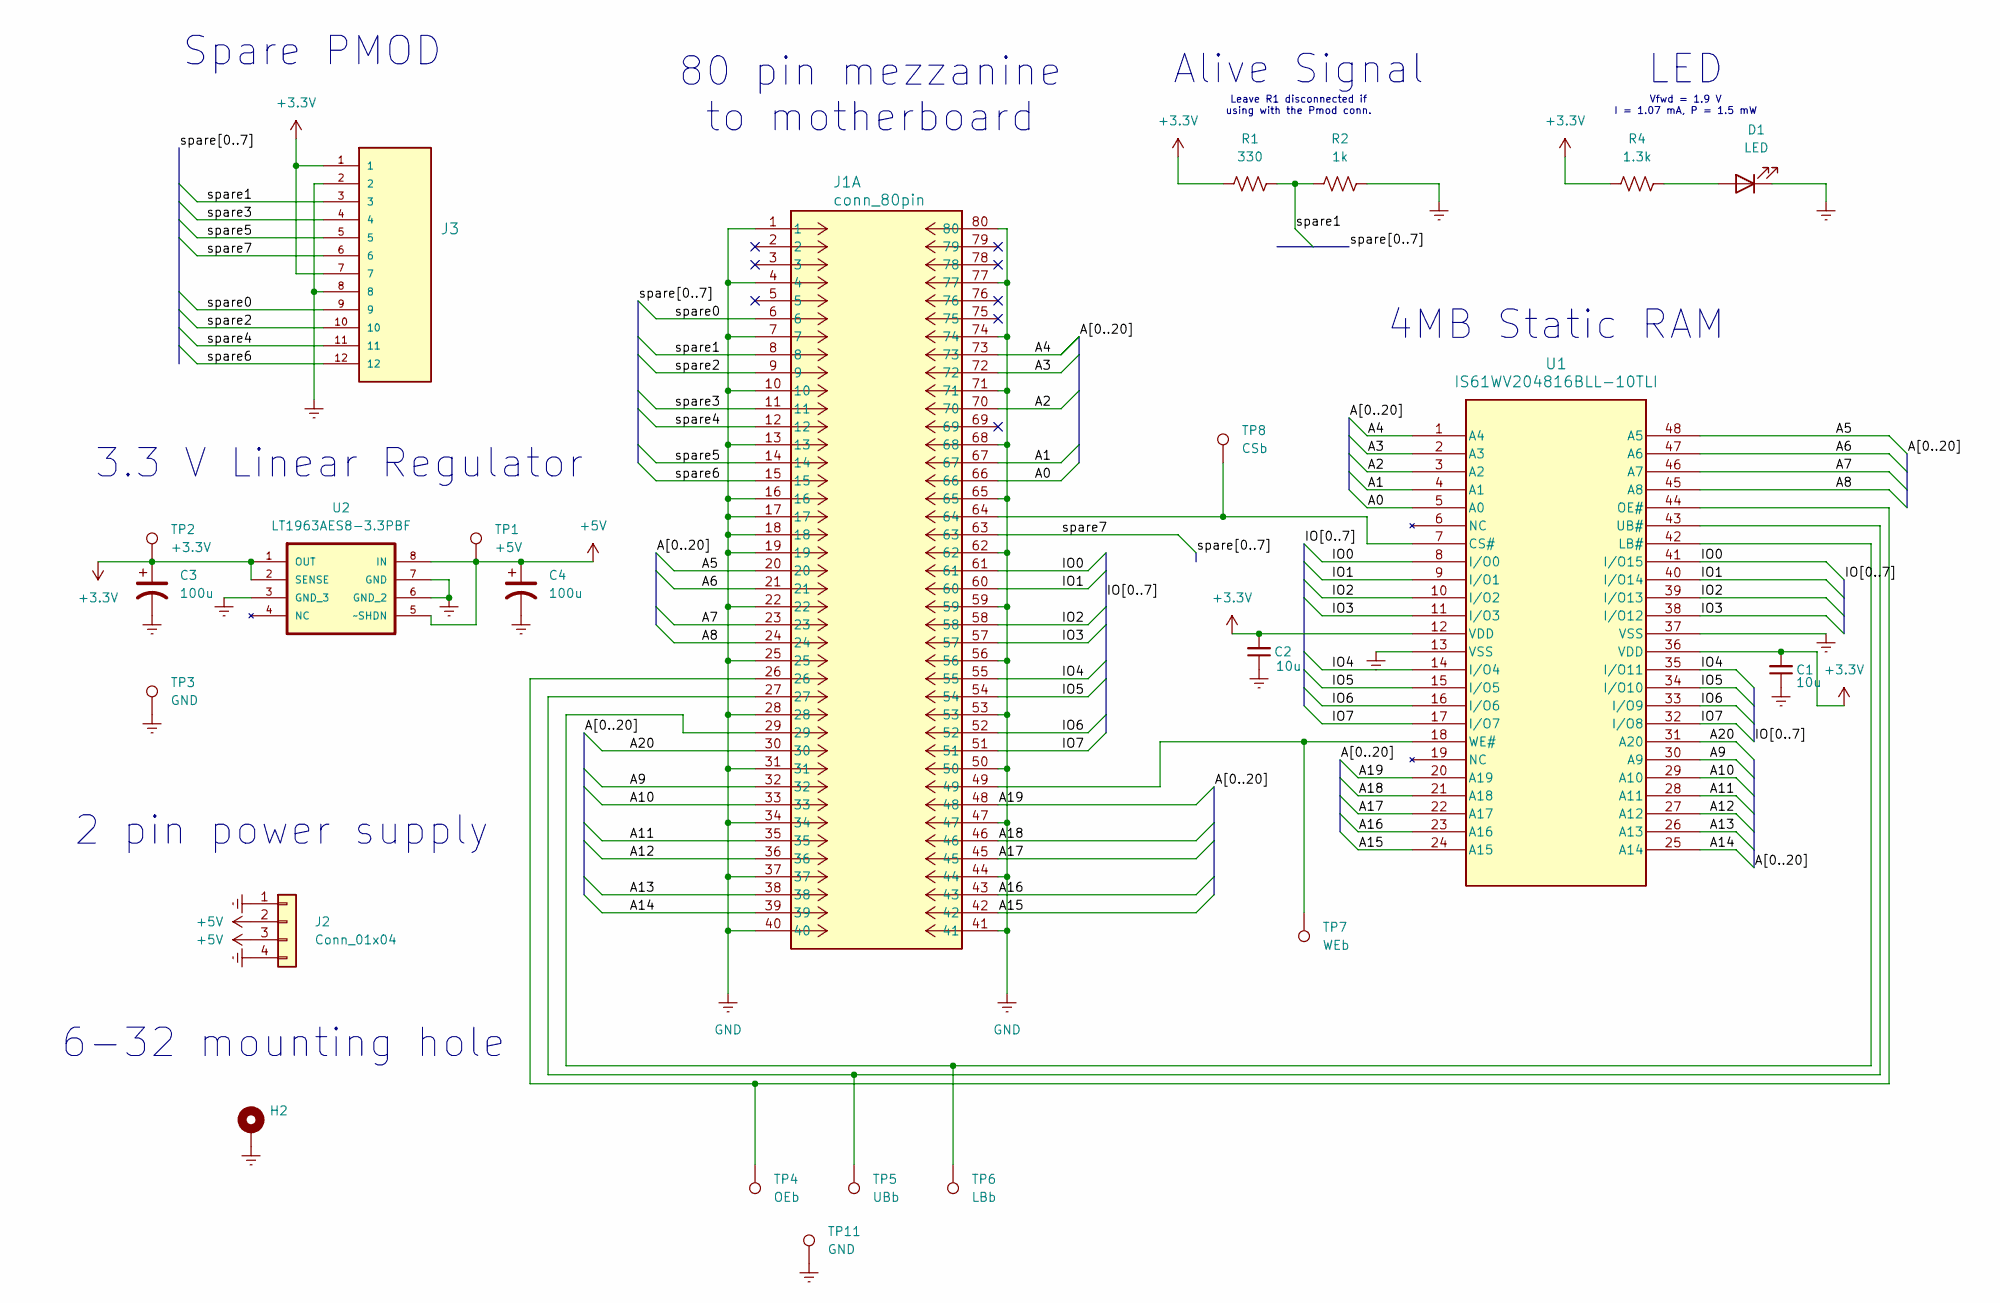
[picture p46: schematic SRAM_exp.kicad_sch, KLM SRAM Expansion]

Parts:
C1, C2: 10u; C_0603_1608Metric
C3, C4: 100u; C_1206_3216Metric
D1: LED; LED_0402_1005Metric_Pad0.77x0.64mm_HandSolder
H2: MountingHole_Pad_Via_6-32_free_fit
J1: conn_80pin; CONN_5177985-3_TYC
J2: Conn_01x04; Molex_01x04_RA_22-05-3041
J3: Pmod_conn; CONN_HEADER_VERT_12POS_2.54MM; PARTREV R
R1: 330; R_0603_1608Metric_Pad0.98x0.95mm_HandSolder
R2: 1k; R_0603_1608Metric_Pad0.98x0.95mm_HandSolder
R4: 1.3k; R_0603_1608Metric_Pad0.98x0.95mm_HandSolder
TP1: +5V; PinHeader_1x01_P1.00mm_Vertical
TP2: +3.3V; PinHeader_1x01_P1.00mm_Vertical
TP3, TP11: GND; PinHeader_1x01_P1.00mm_Vertical
TP4: OEb; TestPoint_THTPad_1.0x1.0mm_Drill0.5mm
TP5: UBb; TestPoint_THTPad_1.0x1.0mm_Drill0.5mm
TP6: LBb; TestPoint_THTPad_1.0x1.0mm_Drill0.5mm
TP7: WEb; TestPoint_THTPad_1.0x1.0mm_Drill0.5mm
TP8: CSb; TestPoint_THTPad_1.0x1.0mm_Drill0.5mm
U1: IS61WV204816BLL-10TLI; 48L_TSOP-1_12X20_ISI
U2: LT1963AES8-3.3PBF; SOIC127P600X175-8N; MPN LT1963AES8-3.3#PBF

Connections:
+3.3V: C1.2, C2.2, C3.1, J3.1, J3.7, R1.1, R4.1, TP2.1 (1_1), U1.12 (VDD), U1.36 (VDD), U2.1 (OUT), U2.2 (SENSE)
+5V: C4.1, J2.2, J2.3, TP1.1 (1_1), U2.5 (~SHDN), U2.8 (IN)
/A0: J1.66, U1.5 (A0)
/A1: J1.67, U1.4 (A1)
/A2: J1.70, U1.3 (A2)
/A3: J1.72, U1.2 (A3)
/A4: J1.73, U1.1 (A4)
/A5: J1.20, U1.48 (A5)
/A6: J1.21, U1.47 (A6)
/A7: J1.23, U1.46 (A7)
/A8: J1.24, U1.45 (A8)
/A9: J1.32, U1.30 (A9)
/A10: J1.33, U1.29 (A10)
/A11: J1.35, U1.28 (A11)
/A12: J1.36, U1.27 (A12)
/A13: J1.38, U1.26 (A13)
/A14: J1.39, U1.25 (A14)
/A15: J1.42, U1.24 (A15)
/A16: J1.43, U1.23 (A16)
/A17: J1.45, U1.22 (A17)
/A18: J1.46, U1.21 (A18)
/A19: J1.48, U1.20 (A19)
/A20: J1.30, U1.31 (A20)
/IO0: J1.61, U1.8 (I/O0), U1.41 (I/O15)
/IO1: J1.60, U1.9 (I/O1), U1.40 (I/O14)
/IO2: J1.58, U1.10 (I/O2), U1.39 (I/O13)
/IO3: J1.57, U1.11 (I/O3), U1.38 (I/O12)
/IO4: J1.55, U1.14 (I/O4), U1.35 (I/O11)
/IO5: J1.54, U1.15 (I/O5), U1.34 (I/O10)
/IO6: J1.52, U1.16 (I/O6), U1.33 (I/O9)
/IO7: J1.51, U1.17 (I/O7), U1.32 (I/O8)
/spare0: J1.6, J3.9
/spare1: J1.8, J3.3, R1.2, R2.1
/spare2: J1.9, J3.10
/spare3: J1.11, J3.4
/spare4: J1.12, J3.11
/spare5: J1.14, J3.5
/spare6: J1.15, J3.12
/spare7: J1.63, J3.6
GND: C1.1, C2.1, C3.2, C4.2, D1.1 (K), H2.1 (1_1), J1.1, J1.4, J1.7, J1.10, J1.13, J1.16, J1.17, J1.18, J1.19, J1.22, J1.25, J1.28, J1.31, J1.34, J1.37, J1.40, J1.41, J1.44, J1.47, J1.50, J1.53, J1.56, J1.59, J1.62, J1.65, J1.68, J1.71, J1.74, J1.77, J1.80, J2.1, J2.4, J3.2, J3.8, R2.2, TP3.1 (1_1), TP11.1 (1_1), U1.13 (VSS), U1.37 (VSS), U2.3 (GND_3), U2.6 (GND_2), U2.7 (GND)
unnamed: D1.2 (A), R4.2
unnamed: J1.64, TP8.1 (1_1), U1.7 (CS#)
unnamed: J1.29, TP6.1 (1_1), U1.42 (LB#)
unnamed: J1.26, TP4.1 (1_1), U1.44 (OE#)
unnamed: J1.27, TP5.1 (1_1), U1.43 (UB#)
unnamed: J1.49, TP7.1 (1_1), U1.18 (WE#)

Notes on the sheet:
Leave R1 disconnected if using with the Pmod conn.
Alive Signal
3.3 V Linear Regulator
Spare PMOD
4MB Static RAM
Vfwd = 1.9 V I = 1.07 mA, P = 1.5 mW
80 pin mezzanine to motherboard
2 pin power supply
6-32 mounting hole
LED

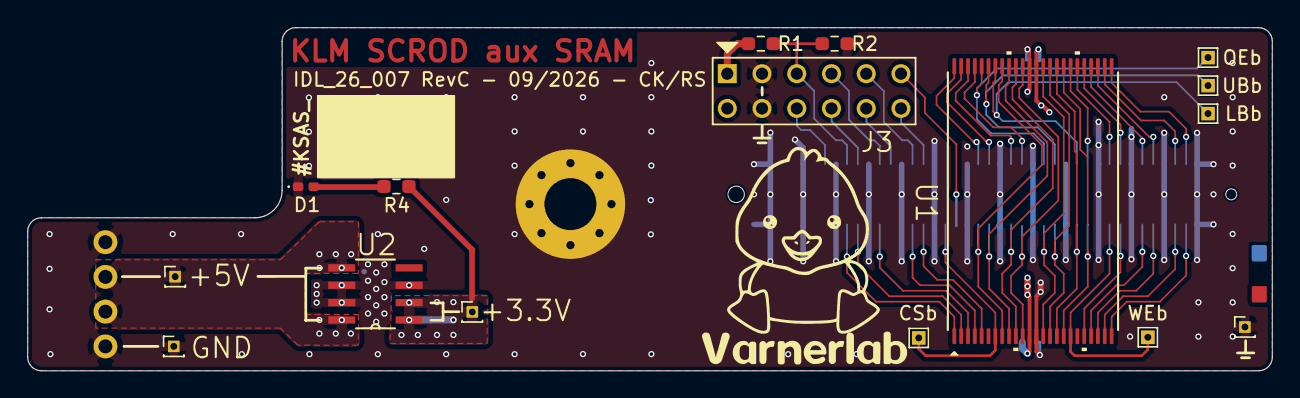
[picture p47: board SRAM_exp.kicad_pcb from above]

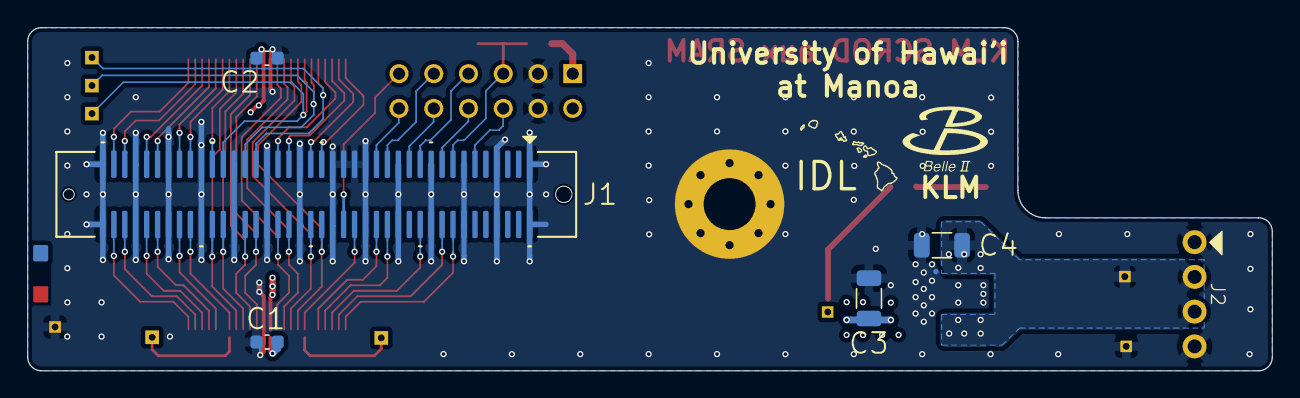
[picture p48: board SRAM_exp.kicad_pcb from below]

Board: 4 copper layers, 91.0 x 25.1 mm, 23 parts (6 on the bottom side), 46 nets.

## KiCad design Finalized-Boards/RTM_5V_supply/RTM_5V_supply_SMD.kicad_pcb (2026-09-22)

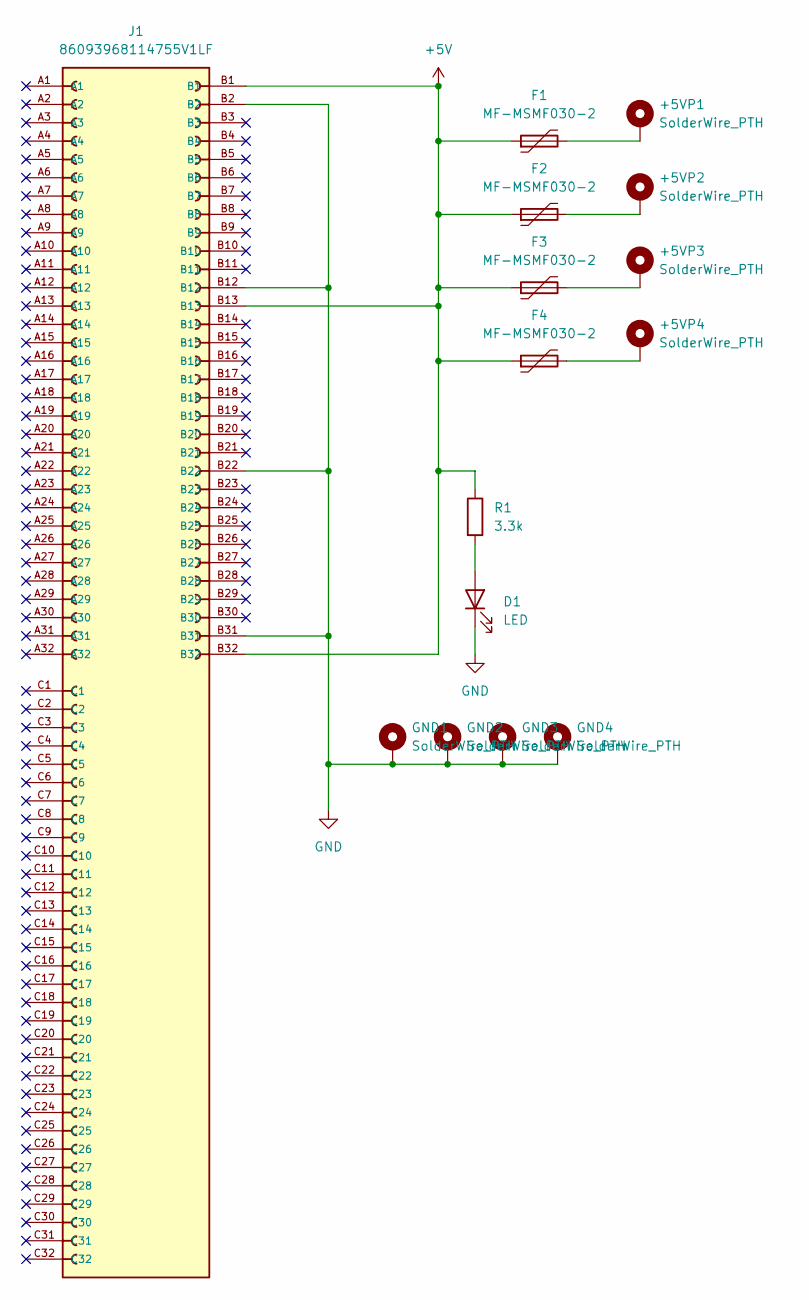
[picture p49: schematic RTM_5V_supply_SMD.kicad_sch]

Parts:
+5VP1, +5VP2, +5VP3, +5VP4: SolderWire_PTH; PTH_12AWG
D1: LED; LED_0402_1005Metric_Pad0.77x0.64mm_HandSolder
F1, F2, F3, F4: MF-MSMF030-2; Fuse_1812_4532Metric
GND1, GND2, GND3, GND4: SolderWire_PTH; PTH_12AWG
J1: 86093968114755V1LF; AMPHENOL_86093968114755V1LF; PARTREV F
R1: 3.3k; R_0603_1608Metric_Pad0.98x0.95mm_HandSolder

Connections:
+5V: F1.1, F2.1, F3.1, F4.1, J1.B1, J1.B13, J1.B32, R1.1
GND: D1.1 (K), GND1.1 (1_1), GND2.1 (1_1), GND3.1 (1_1), GND4.1 (1_1), J1.B2, J1.B12, J1.B22, J1.B31
unnamed: +5VP1.1 (1_1), F1.2
unnamed: +5VP2.1 (1_1), F2.2
unnamed: +5VP3.1 (1_1), F3.2
unnamed: +5VP4.1 (1_1), F4.2
unnamed: D1.2 (A), R1.2

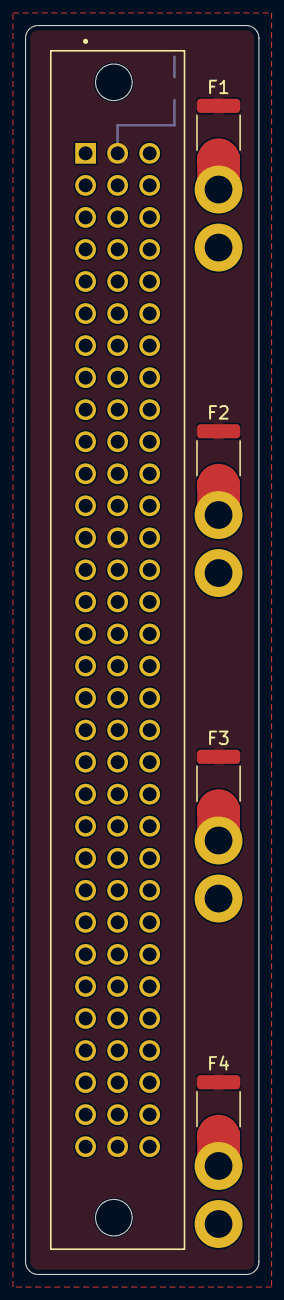
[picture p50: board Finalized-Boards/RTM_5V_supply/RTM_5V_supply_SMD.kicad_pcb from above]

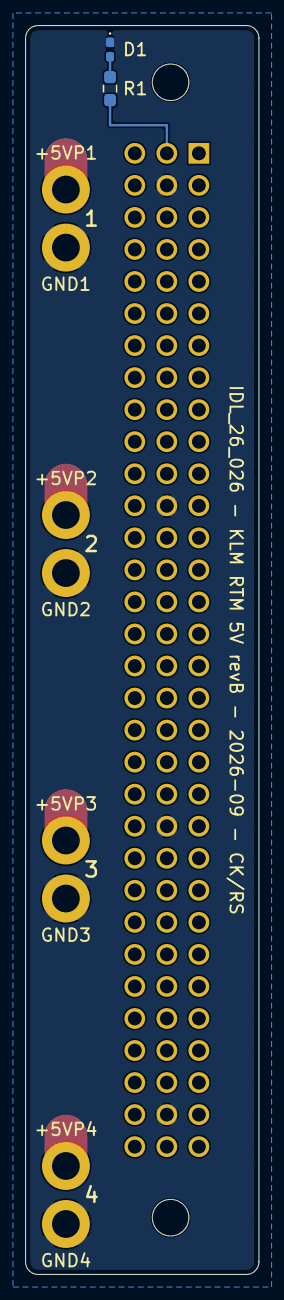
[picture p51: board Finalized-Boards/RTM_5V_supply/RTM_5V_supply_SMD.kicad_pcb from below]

Board: 4 copper layers, 18.5 x 99.0 mm, 15 parts (10 on the bottom side), 7 nets.

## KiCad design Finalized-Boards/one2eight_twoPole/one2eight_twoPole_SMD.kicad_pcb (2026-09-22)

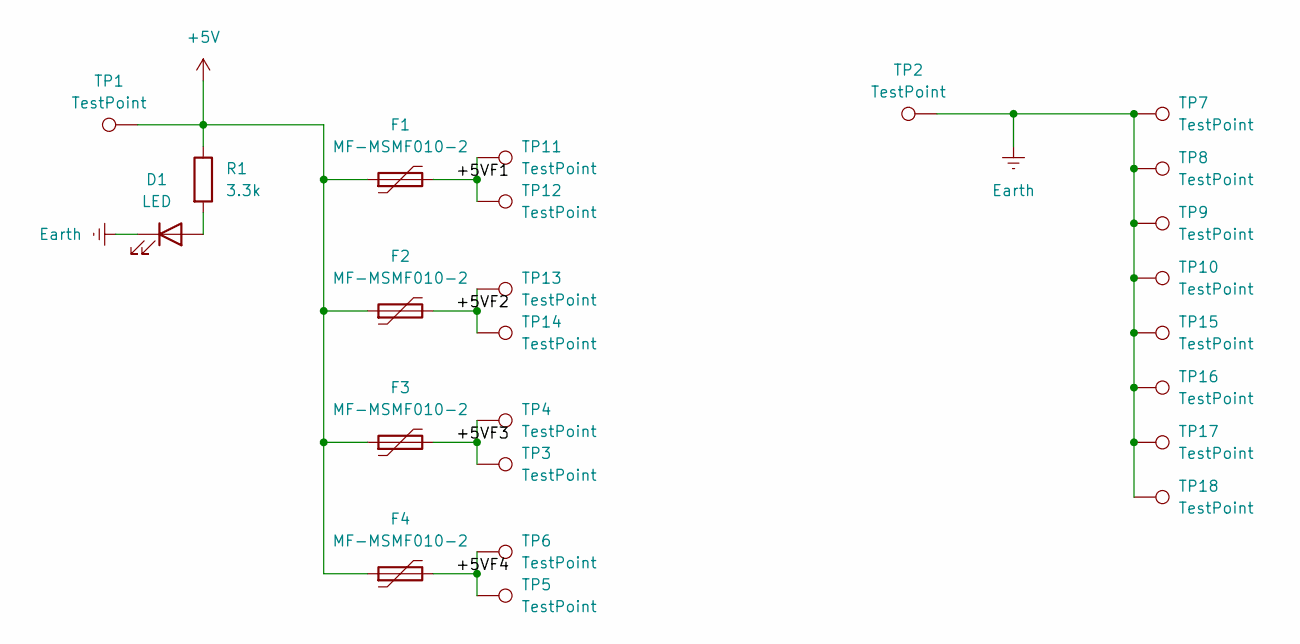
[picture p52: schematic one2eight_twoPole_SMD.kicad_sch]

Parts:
D1: LED; LED_0402_1005Metric_Pad0.77x0.64mm_HandSolder
F1, F2, F3, F4: MF-MSMF010-2; Fuse_1812_4532Metric
R1: 3.3k; R_0603_1608Metric_Pad0.98x0.95mm_HandSolder
TP1, TP2: TestPoint; PTH_12AWG
TP3, TP4, TP5, TP6, TP7, TP8, TP9, TP10, TP11, TP12, TP13, TP14, TP15, TP16, TP17, TP18: TestPoint; SolderWire-0.5sqmm_1x01_D0.9mm_OD2.1mm_Relief_3mm_shorter_v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

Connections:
+5V: F1.1, F2.1, F3.1, F4.1, R1.1, TP1.1 (1_1)
/+5VF1: F1.2, TP11.1 (1_1), TP12.1 (1_1)
/+5VF2: F2.2, TP13.1 (1_1), TP14.1 (1_1)
/+5VF3: F3.2, TP3.1 (1_1), TP4.1 (1_1)
/+5VF4: F4.2, TP5.1 (1_1), TP6.1 (1_1)
Earth: D1.1 (K), TP2.1 (1_1), TP7.1 (1_1), TP8.1 (1_1), TP9.1 (1_1), TP10.1 (1_1), TP15.1 (1_1), TP16.1 (1_1), TP17.1 (1_1), TP18.1 (1_1)
unnamed: D1.2 (A), R1.2

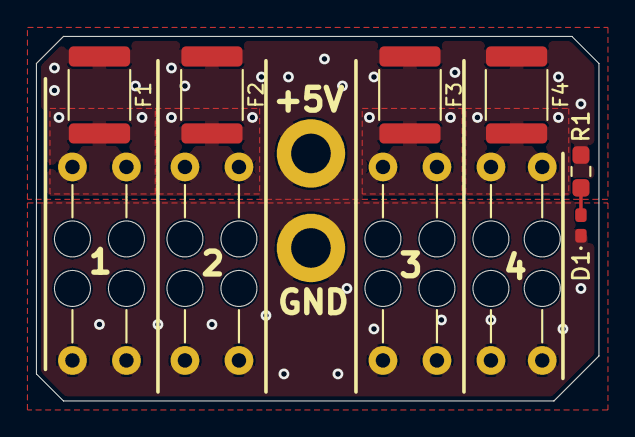
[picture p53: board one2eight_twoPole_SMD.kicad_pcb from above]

Board: 4 copper layers, 31.2 x 20.2 mm, 24 parts (0 on the bottom side), 7 nets.

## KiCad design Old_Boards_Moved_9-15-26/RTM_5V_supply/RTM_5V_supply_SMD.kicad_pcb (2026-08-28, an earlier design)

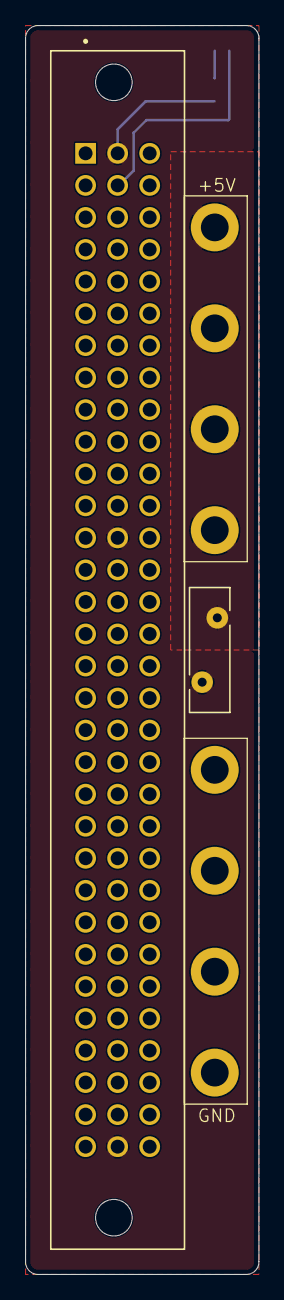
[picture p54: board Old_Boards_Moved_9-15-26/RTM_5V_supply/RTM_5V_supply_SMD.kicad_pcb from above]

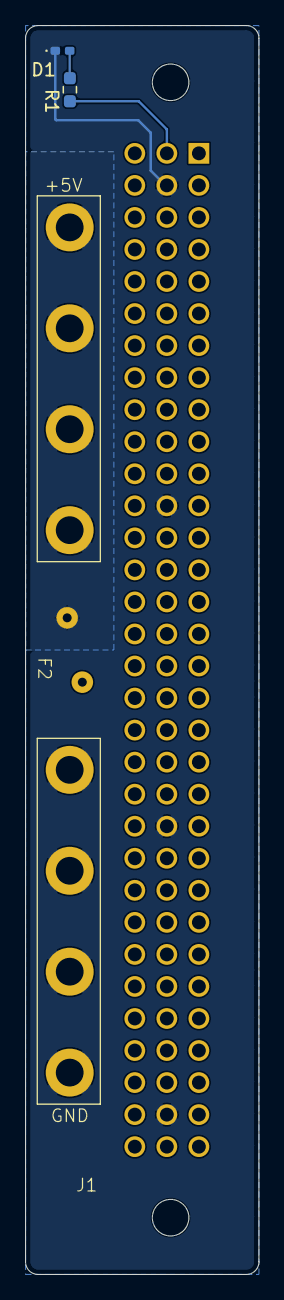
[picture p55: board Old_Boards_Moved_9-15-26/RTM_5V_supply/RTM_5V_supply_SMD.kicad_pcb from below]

Board: 4 copper layers, 18.5 x 99.0 mm, 12 parts (4 on the bottom side), 4 nets.

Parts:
+5VP: MountingHole_Pad; PTH_12AWG
+5VP2, +5VP3, +5VP4: SolderWire_PTH; PTH_12AWG
D1: LED; LED_0402_1005Metric_Pad0.77x0.64mm_HandSolder
F2: Polyfuse; Fuse_Bourns_MF-RHT100
GND: MountingHole_Pad; PTH_12AWG
GND2, GND3, GND4: SolderWire_PTH; PTH_12AWG
J1: 86093968114755V1LF; AMPHENOL_86093968114755V1LF
R1: 3.3k; R_0603_1608Metric_Pad0.98x0.95mm_HandSolder

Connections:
+5V: F2.1, J1.B1, J1.B13, J1.B32, R1.1
+5VP: +5VP.1, +5VP2.1 (1_1), +5VP3.1 (1_1), +5VP4.1 (1_1), F2.2
GND: D1.1 (K), GND.1, GND2.1 (1_1), GND3.1 (1_1), GND4.1 (1_1), J1.B2, J1.B12, J1.B22, J1.B31
unnamed: D1.2 (A), R1.2

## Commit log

2026-08-25 Add Chris Ketter's PCB design resources
    [3544-2.step, 48L_TSOP-1_12X20_ISI.step, A99191CT-ND__CONN_RCPT_80POS_0P8MM.stp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]
2026-08-28 Flatten nested directories, deduplicate slide PDFs
    [3544-2.step, 48L_TSOP-1_12X20_ISI.step, A99191CT-ND__CONN_RCPT_80POS_0P8MM.stp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]
2026-08-28 Reorganize: separate originals, finalized boards, and renders
    [3544-2.step, 48L_TSOP-1_12X20_ISI.step, A99191CT-ND__CONN_RCPT_80POS_0P8MM.stp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]
2026-09-15 Apply Matt's review changes to RTM, fanout and SRAM boards
    SRAM: serial -> IDL_26_007 RevC - 09/2026 - CK/RS; vias untented (board-level);
    GND zone 0.4 clearance / 0.1524 min width; In2 +3.3V stripe pulled back from
    both board edges (tips 103.25 / 126.05) with 45-degree miters; +3.3V via moved
    to (165.54, 125.92) and re-routed on F.Cu/B.Cu to clear GND (was 2 DRC errors);
    C1/C2 0402 -> 0603 X7R in schematic and PCB; orphan teardrop + 2 zero-length
    tracks removed.
    Fanout: Matt's reworked layout (12 AWG input centred, both-side labels, 3 mm
    shorter test points, D1/R1 as real reference designators, silk moved clear).
    RTM: four 1812 1 A PPTCs, one per output; +5V pour full-board on F.Cu/In2,
    GND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
    [C_0402_1005Metric.iam, C_0402_1005Metric.ipt, C_1206_3216Metric.iam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]
2026-09-15 Archive pre-review boards and renders; regenerate renders and DRC reports
    - Old_Boards_Moved_9-15-26/: Finalized-Boards and Finalized-Renders as of 831b2ae
    (also tagged pre-matt-review)
    - Finalized-Renders/: fresh top/bottom renders for all three boards (SRAM added)
    - <board>_DRC.rpt next to each board; SRAM_exp_In2_check.pdf for the GND squeeze
    - finish_9-15.sh: the script that did this
    [3544-2.step, 48L_TSOP-1_12X20_ISI.step, A99191CT-ND__CONN_RCPT_80POS_0P8MM.stp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]
2026-09-16 Matt follow-up: 3.3V zone 0.4 clearance, silk-over-copper ignored, RTM IDL_26_026 silkscreen, fuse part MF-MSMF110/16-2
    [RTM_5V_supply_SMD.kicad_pcb, RTM_5V_supply_SMD.kicad_sch, SRAM_exp.kicad_pcb]
2026-09-16 Refill zones; regenerate SRAM and RTM renders
    [RTM_5V_supply_SMD.kicad_pcb, SRAM_exp.kicad_pcb]
2026-09-17 Matt's 9/17 review: RTM paired 5V/GND terminals, SRAM R1/R2 to 0603, fanout per-destination polyswitches; archive 9/16 boards
    [3544-2.step, 48L_TSOP-1_12X20_ISI.step, A99191CT-ND__CONN_RCPT_80POS_0P8MM.stp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]
2026-09-22 Consolidate archived board revisions under Archive/; archive 1.1 A polyswitch version (tag polyswitch-1.1A)
    [3544-2.step, 48L_TSOP-1_12X20_ISI.step, A99191CT-ND__CONN_RCPT_80POS_0P8MM.stp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]
2026-09-22 Polyswitches sized to load: RTM F1-F4 MF-MSMF110/16-2 -> MF-MSMF030-2 (0.3 A), fanout F1-F4 -> MF-MSMF010-2 (0.1 A); refresh renders and DRC
    [RTM_5V_supply_SMD.kicad_pcb, RTM_5V_supply_SMD.kicad_sch, SRAM_exp.kicad_pcb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]
2026-09-22 Revert archive naming to Old_Boards_Moved_<M-D-YY>/; 1.1 A polyswitch version is Old_Boards_Moved_9-22-26
    [3544-2.step, 48L_TSOP-1_12X20_ISI.step, A99191CT-ND__CONN_RCPT_80POS_0P8MM.stp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]
2026-09-22 Matt's 9/22 review: fanout fuses rotated, thermal-relief zones, stitching vias; SRAM footprints synced with library, sch/pcb parity fixed; add lib tables, schematic PDFs, full-severity DRC/ERC reports
    [RTM_5V_supply_SMD.kicad_pcb, SRAM_exp.kicad_pcb, SRAM_exp.kicad_sch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]
2026-10-20 Archive boards before hand-solderability revision (Old_Boards_Moved_10-20-26)
